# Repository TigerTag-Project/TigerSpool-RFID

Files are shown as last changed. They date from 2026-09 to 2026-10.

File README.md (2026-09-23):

<p align="center">
  <picture>
    <source media="(prefers-color-scheme: dark)"  srcset="assets/logo-tigertag-head-dark.svg">
    <source media="(prefers-color-scheme: light)" srcset="assets/logo-tigertag-head.svg">
    TigerTag
  </picture>
</p>

<h1 align="center">TigerSpool RFID</h1>

<p align="center">
  <strong>Tap a spool on the box. The filament lands in the right printer slot.</strong><br>
  A 2.0" touchscreen, a PN532 reader, and no typing.
</p>

<p align="center">
  
  
  
  
  
</p>

<p align="center">
  <a href="https://tigertag-project.github.io/TigerSpool-RFID/">
    Install TigerSpool from your browser
  </a>
</p>

<p align="center">
  <a href="#what-it-is">What it is</a>
  &nbsp;&middot;&nbsp;
  <a href="#before-you-start">Before you start</a>
  &nbsp;&middot;&nbsp;
  <a href="#quick-start">Quick start</a>
  &nbsp;&middot;&nbsp;
  <a href="#build-it-yourself">Build one</a>
</p>

<p align="center">
  The TigerTag system: a TigerPOD reader, Tiger Studio Manager on a desktop, and the TigerTag app on a phone
</p>

<p align="center">
  <sub>The TigerTag system. A TigerSpool is the device that takes a spool's
  identity and puts it into a printer's slot.</sub>
</p>

---

**TigerSpool RFID** is open-source firmware for a small box that sits next to
your 3D printer. Hold a spool carrying a TigerTag NFC chip against it, pick a
slot on the touchscreen, and the box writes the filament into that slot on the
printer — material, brand, colour and temperatures. No app, no keyboard, no
retyping what the tag already knows.

MIT licensed. Built with PlatformIO for the ESP32-S3.

---

## What it is

Your printer already has a slot list. Your filament already carries its own
identity. TigerSpool is the thirty centimetres between them.

- **Tap a slot, present the spool, done.** There is nothing to confirm: the
  assignment leaves for the printer as soon as the tag is read, over the
  printer's own protocol, and the box tells you which slot to load.
- **Scan mode: what is this spool?** Put one on the reader and the box shows
  what the chip holds - colour, material, brand, the two temperature windows,
  the drying instruction, what is left on it, and whether the tag is certified.
  No printer involved.
- **Your printers come from your account.** They are configured once, in Tiger
  Studio Manager, and every TigerSpool you own reads the same list.
- **It speaks nine languages** - English, French, German, Spanish, Italian,
  Polish, both Portuguese and Chinese - and asks which one before anything else.
- **It updates itself.** Over the air, verified, from this repository's releases.

## Before you start

**This is the part that catches people out, so it is first.**

A TigerSpool has no keyboard and no way to type a printer's address, and that is
deliberate — it reads your printers from your TigerTag account instead. Which
means two things have to exist before the box is useful:

### 1. A TigerTag account, created in Tiger Studio Manager

**[Tiger Studio Manager](https://github.com/TigerTag-Project/TigerTag-Studio-Manager)**
is the desktop application for the ecosystem. Install it and create an account
there. That account is what the TigerSpool signs in to — by e-mail, or with
Google through a QR code, so you never type a password on a 2" screen.

Without an account, the box gets through Wi-Fi setup and then has nothing to
sign in to.

<p align="center">
  Tiger Studio Manager showing a filament library and a printer's slots
</p>

<p align="center">
  <sub>Tiger Studio Manager. Your filaments and your printers live here — the box
  reads this list, it does not build it.</sub>
</p>

### 2. Your printers, added in Tiger Studio Manager

Adding a printer means Tiger Studio finds it on your network, or you enter its
address and access code, and stores it against your account.

**If you have not done this, the printer list on the box will be empty.** That is
not a fault and there is nothing to fix on the device — it is showing you exactly
what your account contains. Add the printer in Tiger Studio, and it appears on
the box at the next sync.

The same is true for the details: the access code, the IP address, the brand and
model all come from there. TigerSpool reads that list; it does not build it.

> **In short:** Tiger Studio Manager → create an account → add your printers →
> *then* set up the box.

## Quick start

### Step 1 — install from your browser

**Plug the board into your computer → click Install → wait a minute.** Use the
button at the top of this page. It writes the bootloader, the partition table,
the boot selector and the firmware.

Chrome, Edge or Opera, on a desktop or laptop. Safari and Firefox do not
implement WebSerial and no mobile browser does — the page says so rather than
failing quietly.

### Step 2 — set it up on the box

1. **Pick your language.** Nine of them, before anything else.
2. **Join Wi-Fi.** The box shows a QR code. Scan it with your phone, and a page
   opens listing the networks it can see. Pick yours, type the password on your
   phone, and the box joins — no reboot, nothing typed on the small screen.
3. **Sign in.** E-mail and password, or Google through a second QR code.
4. **Your printers arrive.** From your account, as configured in Tiger Studio.
   The box's address on your network (`http://tigerspool-xxxx.local/`) shows
   who is signed in, lists those printers with a switch for each, syncs them
   again, and signs out - all from a phone.

Then tap the slot you want and hold a tagged spool against the box. It is sent
to the printer as soon as it is read - there is nothing to confirm - and the
box then tells you where to put it.

That last part is the one people miss: **it tells the printer what the spool
is, it does not load it.** Putting the spool in that slot - the CFS, the AMS,
the ACE unit, whatever your printer calls its tray - is still yours to do.

From then on it updates itself over the air.

### Build it yourself

```bash
git clone https://github.com/TigerTag-Project/TigerSpool-RFID.git
cd TigerSpool-RFID

bash scripts/flash.sh --monitor
```

That builds the firmware, flashes it over USB and opens the serial console.
Requires [PlatformIO Core](https://docs.platformio.org/en/latest/core/installation/).

An ordinary flash **keeps your Wi-Fi credentials, your account session and your
printers** — nothing it writes touches the NVS partition. `--erase` wipes the
chip and is how you get a genuine first-boot again.

## Hardware

One board, one reader, four wires. The electronics are identical for every
printer brand — only the 3D-printed shell changes.

| Qty | Component | Link |
|---|---|---|
| 1 | Waveshare ESP32-S3-Touch-LCD-2 — 240×320 IPS touch, ESP32-S3**R8**, 16 MB flash, 8 MB octal PSRAM. Screen, touch and MCU on one board | [buy](https://link.amazon/B06RoLfDi) |
| 1 | PN532 **V3** NFC module — DIP switches, set to **HSU (UART)**: both switches `0` / OFF, not I²C, not SPI | [buy](https://link.amazon/B0iJgHVtP) |
| 1 | USB-C to USB-A cable **that carries data** — a charge-only cable makes a working board look dead: no serial port ever appears | [buy](https://link.amazon/B00Xg3WT4) |
| — | Four jumper wires — 3V3, GND, TX, RX | ships with the PN532 |
| 1 | 3D-printed case — one per printer brand, plus a desktop stand | [models/](models/) |
| *opt.* | Magnetic USB connector — the port is the one part handled every day; the cable lets go instead of the socket | [buy](https://link.amazon/B0bWVIBa0) |
| *opt.* | 3.7 V 1000 mAh LiPo cell, PH1.25 — charged over USB, and the box runs from it with the cable out. Settings then gains a **Battery** entry; without a cell it is not there. **Check the polarity** | [buy](https://link.amazon/B0fL0jjf3) |

**About 40 €** in total, plus filament.

> Some of the links above are Amazon affiliate links: buying through them pays
> the project a small commission at no cost to you. Nothing on this list is
> chosen because it is affiliated — any equivalent module works.

Full parts list: **[hardware/BOM.md](hardware/BOM.md)** ·
Wiring: **[docs/WIRING.md](docs/WIRING.md)** and **[hardware/pinout.md](hardware/pinout.md)**

<p align="center">
  <a href="docs/WIRING.md">
    Wiring diagram: ESP32-S3-Touch-LCD-2 to PN532 — 3V3, GND, TX to SDA, RX to SCL
  </a>
</p>
<p align="center">
  <sub><a href="https://app.cirkitdesigner.com/project/7a6c0887-8e44-4303-81b3-be51aab4b40a">Interactive schematic in Cirkit Designer</a></sub>
</p>

> **The reader goes on GPIO43/44.** Not GPIO6/7 — that pair is an I²C bus with
> pull-ups on this board. A PN532 wired there powers up, answers, and returns
> random UIDs with failing reads. It looks like a bad tag or a bad antenna. It is
> neither, and it costs a day. Follow [docs/WIRING.md](docs/WIRING.md) exactly.

## Printer support

**"Any printer" is the goal, not a claim about today.** The current state of
every brand is in **[docs/PRINTER-COMPATIBILITY.md](docs/PRINTER-COMPATIBILITY.md)**,
which grades each on three levels — ✅ automatic, ⚙️ one setup step,
🧪 experimental. Read it before buying parts for a specific printer.

| Brand | Firmware support | Transport |
|---|---|---|
| **Creality** | ✅ implemented, proven on hardware | WebSocket |
| **FlashForge** | ✅ implemented, proven on hardware | HTTP |
| **Bambu Lab** | ✅ implemented, proven on hardware - LAN and cloud mode | MQTT over TLS |
| **Snapmaker** | ✅ implemented, proven on hardware | Moonraker over WebSocket |
| **Elegoo** | ✅ implemented, reading proven on hardware | MQTT |
| **Anycubic** | ✅ implemented, reading proven on hardware - LAN mode | MQTT over TLS |

A Bambu Lab printer in **cloud mode** is read-only: its spools are shown, but a
tag cannot be written to it - Bambu's cloud does not accept the command. Switch
the printer to LAN mode to write.

Slot names match the ones the printer and Tiger Studio use — `Ext.` plus
`1A`–`1D` on Creality and FlashForge, `A1`–`A4` then `B1`–`B4` on Bambu,
`E1`–`E4` on Snapmaker, `S1`–`S4` on Elegoo, `A1`–`A4` per ACE unit on
Anycubic. The table and its two traps are in the compatibility document.

## How many printers at once

**The limit is not a number of printers - it is how much memory their
connections take.** One TigerSpool has a fixed budget of **160 load slots**,
where one load slot is one kilobyte of the chip's internal RAM, and each printer
takes what its connection costs:

| Printer | Load slots |
|---|---|
| First Bambu Lab in cloud mode | 50 |
| Each further Bambu Lab in cloud mode | 4 - they share one connection |
| Bambu Lab in LAN mode | 50 |
| Anycubic | 41 |
| Creality | 6 |
| Snapmaker | 5 |
| Elegoo | 3 |
| FlashForge | 2 |

The difference is encryption: a Bambu or an Anycubic talks over TLS, which is
what memory goes on; the others do not. So ten Elegoos fit where three LAN
Bambus do not.

**Settings > Printers** shows how full the budget is as a percentage. A printer
that would not fit is refused when you switch it on, with the reason on the
screen, rather than connecting and failing later. The measurements, the reasons
for 160, and what the budget does not account for are in
**[docs/CONNECTION-BUDGET.md](docs/CONNECTION-BUDGET.md)**.

## Documentation

| | |
|---|---|
| [ARCHITECTURE.md](docs/ARCHITECTURE.md) | Layering, the state machine, why a backend knows nothing about the screen |
| [ONBOARDING.md](docs/ONBOARDING.md) | The first-boot journey, screen by screen |
| [WIFI-PROVISIONING.md](docs/WIFI-PROVISIONING.md) | The QR code and the captive portal |
| [ACCOUNT-PAIRING.md](docs/ACCOUNT-PAIRING.md) | E-mail and Google sign-in, and why RFC 8628 was rejected |
| [ACCOUNT-DATA.md](docs/ACCOUNT-DATA.md) | The shape a printer arrives in |
| [OTA.md](docs/OTA.md) | Partitions, the manifest, and what is settled before the first release |
| [PRINTER-COMPATIBILITY.md](docs/PRINTER-COMPATIBILITY.md) | Per-brand status and slot naming |
| [CONNECTION-BUDGET.md](docs/CONNECTION-BUDGET.md) | How many printers at once: load slots, every measurement behind them, why 160 |
| [PRESENCE.md](docs/PRESENCE.md) | How a box declares itself to the account, so Tiger Studio can list it |
| [WIRING.md](docs/WIRING.md) | The four wires |
| [ROADMAP.md](docs/ROADMAP.md) | What is deliberately not done yet, and what has to be decided first |

Contributors and agents start at **[AGENTS.md](AGENTS.md)** and
**[CODEMAP.md](CODEMAP.md)**.

## Known limitations

Written down rather than discovered.

- **The firmware is not signed.** Its update connection is verified against the
  root certificate store, so the box knows who it is talking to — but not who
  produced the image. The reasoning and the condition for changing that are in
  [docs/OTA.md](docs/OTA.md).
- **At most three printers that use TLS at once** - Bambu Lab in LAN mode and
  Anycubic, with every cloud Bambu on an account counting as one. It is the
  chip's internal RAM, and the load budget enforces it; see
  [docs/CONNECTION-BUDGET.md](docs/CONNECTION-BUDGET.md). The two ways past it
  are in [docs/ROADMAP.md](docs/ROADMAP.md).
- **A battery has to be declared, in Settings.** The board has no way to tell
  whether a cell is on its connector - no sense line, and the two indirect
  signals were each measured wrong on real hardware - so it asks instead of
  guessing. Until someone answers, it reports no battery.
- **Anycubic in cloud mode is not supported**, only LAN mode.
- **A printer is identified by its position in your account's list.** Reordering
  it in Tiger Studio can move a per-printer setting to the wrong machine. Tracked
  in [docs/reviews/](docs/reviews/).

## Part of the TigerTag ecosystem

TigerTag is an open NFC identification standard for 3D-printing materials. A
spool carries its own identity, and every device in the system reads the same
one.

- **[Tiger Studio Manager](https://github.com/TigerTag-Project/TigerTag-Studio-Manager)** — desktop printer and filament manager. **Start here**: it is where an account is created and printers are declared.
- **[TigerTag-RFID-Guide](https://github.com/TigerTag-Project/TigerTag-RFID-Guide)** — the protocol specification and public registry
- **[TigerSystem-Docs](https://github.com/TigerTag-Project/TigerSystem-Docs)** — ecosystem source of truth
- **[Tiger-Scale-V3](https://github.com/TigerTag-Project/Tiger-Scale-V3)** — the connected filament scale
- **[TigerPOD](https://github.com/TigerTag-Project/TigerPOD)** — open desktop NFC reader/writer
- **SDKs** — [Python](https://github.com/TigerTag-Project/TigerTag-SDK-Python) · [JavaScript](https://github.com/TigerTag-Project/TigerTag-SDK-JS)

## Contributing

Issues and pull requests are welcome. [CONTRIBUTING.md](CONTRIBUTING.md) has the
conventions; the short version is that `bash scripts/verify.sh` passes before
anything is reported as done, and everything committed is in English.

Security reports: [SECURITY.md](SECURITY.md).

## License

[MIT](LICENSE) — build it, sell it, fork it.

Third-party components keep their own licenses; see
[THIRD_PARTY_LICENSES.md](THIRD_PARTY_LICENSES.md). "TigerTag" and "TigerSpool"
are project names, not a license to imply endorsement — the terms for using them
on a product you sell are in [TRADEMARK.md](TRADEMARK.md).

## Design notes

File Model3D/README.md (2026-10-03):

# 3D-printable cases

**The [desktop stand](0.Desktop/) is the base model.** It stands beside any
printer, and it is the one to print if you are not sure. Every other model is a
**printer integration**: the same TigerSpool in a shell that clips onto one
printer's own screen.

<p align="center">
  The desktop stand, spool on the left and spool on the right
</p>

| Model | Kind | MakerWorld | Files |
|---|---|---|---|
| Desktop stand, spool on the left | base, any printer | [print it](https://makerworld.com/models/3360492-tigerspool-desktop-stand-spool-on-the-left) | [`0.Desktop/`](0.Desktop/) |
| Desktop stand, spool on the right | base, any printer | [print it](https://makerworld.com/models/3360619-tigerspool-desktop-stand-spool-on-the-right) | [`0.Desktop/`](0.Desktop/) |
| Creality K2, K2 Pro | integration, clips onto the screen | [print it](https://makerworld.com/models/3361291-tigerspool-for-creality-k2-and-k2-pro) | [`2.Creality/K2-K2Pro/`](2.Creality/K2-K2Pro/) |
| FlashForge Creator 5, 5 Pro | integration, clips onto the screen | [print it](https://makerworld.com/models/3361301-tigerspool-rfid-for-flashforge-creator-5-and-5-pro) | [`4.FlashForge/Creator5-5Pro/`](4.FlashForge/Creator5-5Pro/) |
| Bambu Lab A1, A2L | integration, clips onto the screen | not yet | [`1.BambuLab/A1-A2/`](1.BambuLab/A1-A2/) |
| Anycubic Kobra 3, every model | integration, clips onto the screen | not yet | [`6.Anycubic/Kobra3-Series/`](6.Anycubic/Kobra3-Series/) |

Each brand directory lists its models. On MakerWorld every page carries the
full Bambu Studio project and the whole build guide; the bare parts, the other
slicers' projects and the Fusion sources are here.

---

## The rule that governs every model in this directory

**Only the shell changes. The electronics, the wiring and the connectors are
strictly identical across every model.**

Same Waveshare ESP32-S3-Touch-LCD-2. Same PN532. Same four wires on the same pins.
Same USB-C entry. A TigerSpool built for a Bambu Lab and one built for a Creality
are the same device in a different jacket, and either firmware image runs on
either one.

This is not a convention. It is what makes the project shippable:

- **One firmware.** No per-model build, no variant to pick in the installer, no
  way to flash the wrong image.
- **One bill of materials.** [../hardware/BOM.md](../hardware/BOM.md) is complete
  for every model.
- **One set of wiring instructions.** [../docs/WIRING.md](../docs/WIRING.md)
  is correct for every model.
- **Anyone can add a model** without touching a line of code.

A design that needs a different board, a different reader, extra components, or a
change to the pinout **is not a TigerSpool model**. It is a fork, and it is
welcome as one — under a different name.

---

## What each model has to do

Different only in how it mounts. Every one of them has to:

| Requirement | Why |
|---|---|
| Hold the PN532 antenna **2–4 cm** from where a spool naturally rests | That is the reader's entire range ([../docs/WIRING.md](../docs/WIRING.md)) |
| Keep the antenna **away from the display's metal back** and any ground plane | Both destroy what little range there is |
| Present the 2.0" screen at a readable, tappable angle | It is a touchscreen, used standing up |
| Leave the USB-C port reachable | Power, and recovery flashing |
| Print without supports where possible, and on a printer of the brand it is for | It is a case for that printer; it should print on it |
| Say clearly **where to hold the spool** | Moulded, embossed, or an obvious surface — not in a manual |

---

## Directory layout

```
Model3D/
├── TEMPLATE.md                the README every model starts from
├── 0.Desktop/                 free-standing, fits any printer - the universal one
├── 1.BambuLab/                one numbered directory per brand ...
│   ├── README.md              ... listing its models
│   └── X1C/                   ... and one directory per printer model
├── 2.Creality/
├── 3.Snapmaker/
├── 4.FlashForge/
├── 5.Elegoo/
└── 6.Anycubic/
```

Two levels, and only two: **brand, then printer model.** A case that fits a
whole range goes in the brand directory under the name of that range (`P1/`
for the P1P and the P1S); one that fits a single machine takes that machine's
name (`K2-Plus/`). A model that fits every printer is not a brand model at all:
it belongs in `0.Desktop/`, or next to it.

**A directory here is about physical mounting, not firmware support.** A case
can be designed for a printer before its network protocol works, so a directory
existing says nothing about whether the device talks to that printer.
[../docs/PRINTER-COMPATIBILITY.md](../docs/PRINTER-COMPATIBILITY.md) is the
authority on what actually works.

### What goes in a model directory

```
K2-Plus/
├── README.md                  from ../TEMPLATE.md
├── Images/                    what it looks like - a photo beats a render
├── Source/                    the editable design: .step, .f3d
├── OriginalFiles/             the parts as exported, one file each, no slicer settings
├── BambuStudio/               one directory per slicer the project is saved from
│   └── *.3mf
└── CrealityPrint/
    └── *.3mf
```

| What | Why |
|---|---|
| `README.md` | Which printers it fits, what to print and in what, how it goes together |
| `Images/` | Nobody downloads a case they cannot see. The slicer's own previews can be taken out of a 3MF (`Metadata/plate_1.png`, `top_1.png`) until there is a photo |
| `Source/` | So the next person can adapt it instead of starting again. `.step` opens everywhere; a native file (`.f3d`) is welcome beside it |
| `OriginalFiles/` | The bare parts, for any slicer and any printer |
| `<Slicer>/*.3mf` | A 3MF saved from a slicer carries the orientation, the supports and the plate for that slicer's printers, and is tied to it. One directory per slicer: `BambuStudio/`, `CrealityPrint/`, `FlashStudio/`, `OrcaSlicer/`, `PrusaSlicer/` |

Variants of one design (the desktop stand with the spool on the left or on the
right) are told apart by the file name, or by a `Left/` and `Right/` level where
there are several files per variant.

### Names

**Directories** are written to be read: capitals where they help (`BambuStudio`,
`OriginalFiles`, `K2-Plus`), a number in front of the top-level ones to set
their order. **Files** are lower case with hyphens:
`tigerspool-<model>-<variant>-<part>.3mf`, for example
`tigerspool-desk-left-display-cover.3mf`. **No spaces anywhere**: a space breaks
every link to the path in a README. `scripts/check-models.py` enforces all
three.

### Before a photo is committed

A phone photo records the phone, the time and **the GPS position it was taken
at**. Publish a copy with none of it, scaled to something a page can load:

```bash
ffmpeg -i IMG_1234.jpeg -vf "scale='min(2000,iw)':-2" -map_metadata -1 -q:v 3 \
    Model3D/<Brand>/<Model>/Images/tigerspool-<model>-photo-<view>.jpg
```

`-map_metadata -1` drops the metadata; ffmpeg applies the phone's rotation to
the pixels first, so the picture stays the right way up. Look at the
background too: a photo on a desk shows whatever else is on that desk.
`verify.sh` refuses a picture that still carries EXIF.

### Before a 3MF is committed

A slicer project records more than geometry. It keeps the **full path** of the
file each object was imported from - a user name and a folder layout, on a
public repository - and every object's name as the designer typed it.

```bash
python3 scripts/clean-3mf.py Model3D/<Brand>/<Model>/<Slicer>/*.3mf
```

cuts every source path down to its file name and prints every object name, so
you read them before anyone else does. `verify.sh` refuses a 3MF that still
carries a path.

## Contributing a model

1. Read the rule at the top. If your design needs different electronics, it is a
   fork, not a model.
2. **Print it and build one.** Fit, screen angle and read distance are not
   things a render tells you.
3. **Measure the read distance through the shell.** A case that pushes the
   antenna past ~4 cm produces a device that looks fine and reads nothing.
4. Copy [TEMPLATE.md](TEMPLATE.md) to your directory as `README.md` and fill
   it in: print settings, a photo, which printers it fits.
5. Include the editable source (`.step`, and the native file if you have one)
   so the next person can adapt it.
6. Run `scripts/clean-3mf.py` on your projects, then `bash scripts/verify.sh --quick`.
7. Add a row to the brand's README, and open a PR. See [../CONTRIBUTING.md](../CONTRIBUTING.md).

A model that has been printed and used beats a model that has been designed.

---

## Licensing

Model files contributed here are MIT-licensed like the rest of the repository
([../LICENSE](../LICENSE)). Do not contribute geometry derived from a
manufacturer's proprietary CAD, or from a model whose own license does not permit
redistribution.

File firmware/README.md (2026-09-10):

# firmware/

The TigerSpool firmware: one PlatformIO project, one environment, `tigerspool`,
for the Waveshare ESP32-S3-Touch-LCD-2 with a PN532 reader.

## Layout

```
firmware/
├── platformio.ini          env: tigerspool
├── partitions.csv          two OTA slots, frozen - docs/OTA.md
├── include/                board and LVGL configuration, generated headers
│   ├── version.h           TIGERSPOOL_FW_VERSION, the one version macro
│   └── tigertag_db.h       generated from tools/tigertag_db - never hand-edited
├── lib/
│   └── PN532/              vendored reader driver - ONE copy, patches documented
├── tools/tigertag_db/      mirror of the public TigerTag reference tables
└── src/
    ├── main.cpp            the state machine and the only writable device state
    ├── printer.h           the backend interface and the printer record
    ├── printer_budget.h    how many printers at once - docs/CONNECTION-BUDGET.md
    ├── backend_*.cpp       one backend per brand, one object per printer
    ├── bambu_cloud.cpp     the TLS session every cloud Bambu on an account shares
    ├── reader.cpp          PN532 use, TigerTag decoding
    ├── tigertag_cloud.cpp  account sign-in, pairing, printer import
    ├── tt_db.cpp           reference-table lookups, compiled and downloaded
    ├── webcfg.cpp          captive portal, LAN page, /screen.bmp, /api/*
    ├── i18n.cpp            every on-screen string, in eight languages
    ├── net/                captive DNS, OTA, TLS helpers
    └── ui/                 LVGL screens, theme, icons, generated fonts
```

What each file owns, what it must not be asked to do, and the landmines to read
before editing it are in [../CODEMAP.md](../CODEMAP.md). This tree is the
overview; the map is the reference.

## Rules for this tree

**No credentials, ever.** Not Wi-Fi, not printer access codes, not API keys with
authority. Everything comes from NVS at runtime. The published binary is the same
for every user. See [../SECURITY.md](../SECURITY.md).

**One copy of the vendored library.** The prototype carries three, which have
already drifted into different behaviour —
[../docs/MIGRATION.md](../docs/MIGRATION.md#the-vendored-pn532-library). Patches
to a vendored library carry a comment saying what breaks without them.

**English only.** Comments, identifiers, log messages, commit messages.
User-facing strings go through the i18n layer (`i18n.cpp`), in every language
at once.

**Hardware facts get a comment explaining why.** Every constant that looks
arbitrary — a delay, a page range, a retry count — is arbitrary-looking because
it was expensive to find. Say what breaks if it changes.

## Build

```bash
pio run -e tigerspool                 # compile
bash ../scripts/flash.sh --monitor    # build, flash over USB, open the console
bash ../scripts/verify.sh             # the guards CI runs, plus a build
```

`flash.sh` checks the board's MAC before writing, so it cannot flash the wrong
device on a bench with several plugged in.

Most users will never do this — they install from the browser, and after that
the device updates itself over the air ([../docs/OTA.md](../docs/OTA.md)).

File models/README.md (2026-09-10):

# 3D-printable cases

> **Status: empty.** The directory structure and the rules are here. No model
> files exist yet.

---

## The rule that governs every model in this directory

**Only the shell changes. The electronics, the wiring and the connectors are
strictly identical across every model.**

Same Waveshare ESP32-S3-Touch-LCD-2. Same PN532. Same four wires on the same pins.
Same USB-C entry. A TigerSpool built for a Bambu Lab and one built for a Creality
are the same device in a different jacket, and either firmware image runs on
either one.

This is not a convention. It is what makes the project shippable:

- **One firmware.** No per-model build, no variant to pick in the installer, no
  way to flash the wrong image.
- **One bill of materials.** [../hardware/BOM.md](../hardware/BOM.md) is complete
  for every model.
- **One set of wiring instructions.** [../docs/WIRING.md](../docs/WIRING.md)
  is correct for every model.
- **Anyone can add a model** without touching a line of code.

A design that needs a different board, a different reader, extra components, or a
change to the pinout **is not a TigerSpool model**. It is a fork, and it is
welcome as one — under a different name.

---

## What each model has to do

Different only in how it mounts. Every one of them has to:

| Requirement | Why |
|---|---|
| Hold the PN532 antenna **2–4 cm** from where a spool naturally rests | That is the reader's entire range ([../docs/WIRING.md](../docs/WIRING.md)) |
| Keep the antenna **away from the display's metal back** and any ground plane | Both destroy what little range there is |
| Present the 2.0" screen at a readable, tappable angle | It is a touchscreen, used standing up |
| Leave the USB-C port reachable | Power, and recovery flashing |
| Print without supports where possible, and on a printer of the brand it is for | It is a case for that printer; it should print on it |
| Say clearly **where to hold the spool** | Moulded, embossed, or an obvious surface — not in a manual |

---

## Directory layout

```
models/
├── desktop/      free-standing, sits on a bench or desk — the universal one
├── bambulab/     mounts to a Bambu Lab printer or AMS
├── creality/     mounts to a Creality printer or CFS
├── snapmaker/    mounts to a Snapmaker
├── flashforge/   mounts to a FlashForge
├── elegoo/       mounts to an Elegoo
└── anycubic/     mounts to an Anycubic
```

**A directory here is about physical mounting, not firmware support.** A case
can be designed for a printer before its network protocol works, so a directory
existing says nothing about whether the device talks to that printer.
[../docs/PRINTER-COMPATIBILITY.md](../docs/PRINTER-COMPATIBILITY.md) is the
authority on what actually works.

### What goes in a model directory

| File | |
|---|---|
| `README.md` | Which printers it fits, print settings, assembly notes, photo |
| `*.3mf` | Preferred — carries orientation, supports and plate layout |
| `*.stl` | One per part, pre-oriented for printing |
| `*.step` | Editable source, if available. Please include it. |

`desktop/` is the reference. Start there when designing a new one.

---

## Contributing a model

1. Read the rule at the top. If your design needs different electronics, it is a
   fork, not a model.
2. **Print it and build one.** Fit, screen angle and read distance are not
   things a render tells you.
3. **Measure the read distance through the shell.** A case that pushes the
   antenna past ~4 cm produces a device that looks fine and reads nothing.
4. Add a `README.md` with print settings, a photo, and which printers it fits.
5. Include editable source (`.step` or `.3mf`) so the next person can adapt it.
6. Open a PR. See [../CONTRIBUTING.md](../CONTRIBUTING.md).

A model that has been printed and used beats a model that has been designed.

---

## Licensing

Model files contributed here are MIT-licensed like the rest of the repository
([../LICENSE](../LICENSE)). Do not contribute geometry derived from a
manufacturer's proprietary CAD, or from a model whose own license does not permit
redistribution.

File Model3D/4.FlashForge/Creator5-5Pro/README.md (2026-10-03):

# FlashForge Creator 5 and Creator 5 Pro

The case on a Creator 5 Pro, clipped onto its screen Close-up of the case on the printer

**Print it from MakerWorld:
[TigerSpool for FlashForge Creator 5 and 5 Pro](https://makerworld.com/models/3361301-tigerspool-rfid-for-flashforge-creator-5-and-5-pro)**

A printer integration of the [desktop stand](../../0.Desktop/) for the
FlashForge Creator 5 and Creator 5 Pro: the same TigerSpool, in a case that
clips onto the printer's screen, with the TigerSpool screen and the reader
beside it - where the spools go into slots 1A to 1D.

## Recommended: the FlashForge × TigerSystem firmware

TigerSpool talks to the printer over your local network. With FlashForge's
standard firmware, **turning LAN mode on turns FlashForge Cloud off**. The
FlashForge × TigerSystem firmware - an official FlashForge build, developed by
their engineering team at TigerTag's request - keeps both on at once. It is
free.

| | Standard firmware | FlashForge × TigerSystem |
|---|---|---|
| FlashForge Cloud - app, remote access | ✓ | ✓ |
| LAN - local tools on your network | ✓ | ✓ |
| Both at the same time | ✕ | ✓ |
| Tiger Studio, Tiger NFC Connect and TigerSpool with Cloud on | ✕ | ✓ |

Download: [Creator 5](https://tigertag-project.github.io/FlashForge-TigerTag-Creator5-Firmware-Lan-and-Cloud/download/creator5/) ·
[Creator 5 Pro](https://tigertag-project.github.io/FlashForge-TigerTag-Creator5-Firmware-Lan-and-Cloud/download/creator5pro/).
It installs from a FAT32 USB drive, the file at its root, printer off; switch
on and it installs itself. Then turn LAN mode on. **Do not accept the printer's
own online update afterwards** - it puts the standard firmware back, and Cloud
+ LAN with it; reinstall from USB if it happened.

Thank you, FlashForge: opening a printer to an ecosystem that is not your own
is a rare decision.

## Parts

| Part | File |
|---|---|
| Frame | [`tigerspool-creator5-frame.3mf`](OriginalFiles/tigerspool-creator5-frame.3mf) |
| Cover | [`tigerspool-creator5-cover.3mf`](OriginalFiles/tigerspool-creator5-cover.3mf) |
| RFID reader holder | [`tigerspool-creator5-rfid.3mf`](OriginalFiles/tigerspool-creator5-rfid.3mf) |
| Everything, one plate (Bambu Studio) | [`tigerspool-creator5-full.3mf`](BambuStudio/tigerspool-creator5-full.3mf) |
| Everything, one plate (FlashForge's Flash Studio, for the Creator 5) | [`tigerspool-creator5-full.3mf`](FlashStudio/tigerspool-creator5-full.3mf) |

The bare parts carry geometry only, for any slicer; the two slicer projects
carry the orientation, the supports and the settings below.

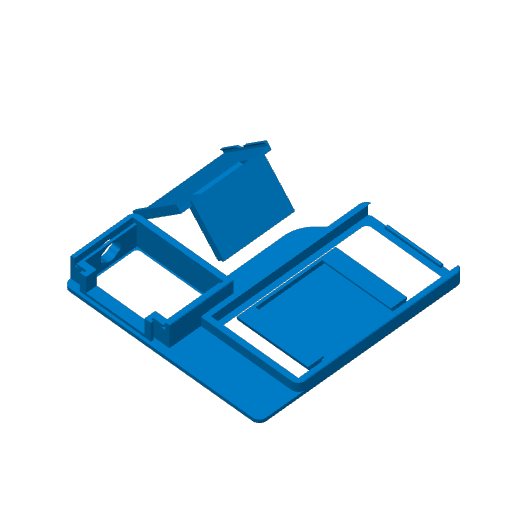
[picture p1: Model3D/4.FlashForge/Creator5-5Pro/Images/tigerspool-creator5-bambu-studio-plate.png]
The parts on the Bambu Studio plate


## Print settings

| Setting | Bambu Studio | Flash Studio |
|---|---|---|
| Printer | A1 mini, 0.4 mm nozzle | Creator 5, 0.4 mm nozzle |
| Layer height | 0.20 mm | 0.08 mm |
| Walls | 3 | 2 |
| Infill | 15 % | 15 % |
| Supports | tree, placed by hand - they are in the project | the same |
| Material | PLA (Bambu PLA Basic in the project), two colours | PLA |

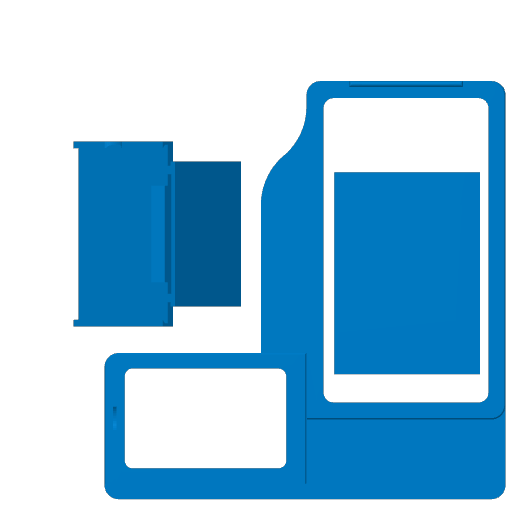
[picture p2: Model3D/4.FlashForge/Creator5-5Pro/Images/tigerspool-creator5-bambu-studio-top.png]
The plate from above


## Source

[`Source/tigerspool-creator5.f3d`](Source/tigerspool-creator5.f3d) - the Fusion design.

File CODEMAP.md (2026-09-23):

# Code map

**The [Landmines](#landmines) table is this file.** Everything above it is the
short list of module facts that `ls` and `grep` do not give you; everything a
grep would have told you has been deliberately left out.

No line numbers are recorded here: nothing verifies them, and a number nothing
verifies is a number that lies. Grep for the symbol. If a file has outgrown what
this says, say so rather than working around it.

Build-level and hardware-level facts live in [CLAUDE.md](CLAUDE.md) and are not
repeated here.

## Modules worth a note

| File | What is not obvious |
|---|---|
| `main.cpp` | Owns the state machine and the only writable copy of device state — and also owns the display device itself (`lcd`, and the PSRAM `canvas` sprite that exists solely so `/screen.bmp` has something to serialise). It draws no widgets, and must not start: screens render from state passed in. It also carries an inline Creality LAN scanner, which is not where anyone looks for it. |
| `webcfg.cpp`, account page | Signed in, `/login` is the account page, and it **never syncs or switches anything itself**. Its handlers run on the loop task: a sync there nested a TLS handshake in a web handler, overflowed the loop's 8 KB stack on every email sign-in, and held the screen still for the whole sync. So a handler calls `ttcloud::requestSync()` and the loop starts the task; a printer switch is a mask read by `takePrinterSwitch()` and applied by `main.cpp` through `tryToggle()`, the device's own switch and budget check. `/api/account` answers anyone on the LAN, so it carries names, brands and addresses and never a serial or an access code. |
| `webcfg.cpp` | Serves **two** web interfaces — the captive portal for setup, and a separate legacy configuration page over the LAN once provisioned — and has **two** independent Wi-Fi scanners, one async and JSON for the portal, one blocking and HTML for the legacy page. "Change the web page" or "fix the scan" usually means changing the wrong one. |
| `tt_db.cpp` | The TigerTag reference tables exist **twice**, and every lookup goes through here rather than through `tigertag_db.h`. The compiled tables are the floor - what a brand-new box knows offline - and the downloaded ones in LittleFS are preferred when they parse. The fallback is per table, not all-or-nothing, so a corrupt brand file does not throw away a good material file. Calling `tt_material()` directly bypasses the whole mechanism and looks identical until a spool from last month reads as `brand#48804`. The material table keeps more than labels - `crealityID`, `crealityPressureAdvance` and the recommended nozzle window, in the download and in `TT_MATERIAL_INFO` - and `materialInfo()` answers from the same layer as `material()`. |
| `printer_budget.h` | Decides whether a printer may be **switched on**, in *load slots* - one is a kilobyte of internal RAM. It never sees memory: the prices are constants taken from `/api/memtest`, and `docs/CONNECTION-BUDGET.md` holds the measurements they must stay equal to. A new brand with no entry in `loadSlotsFor()` costs 0 and is never refused. "Load slot", never plain "slot" - a slot is a spool tray everywhere else in this code. |
| `backend_bambu.cpp`, external spool | **Read as ams 255 / tray 254, written as ams 255 / tray 0 / slot 0.** A write to tray 254 is accepted and ignored by current firmware (X1C 01.12). The first report after a new MQTT connection carries an empty external tray before the real one. |
| `bambu_cloud.cpp` | One MQTT/TLS session shared by **every** cloud Bambu on the account; `backend_bambu.cpp` attaches and detaches, ref-counted. Reports are routed by the serial in the topic and nothing else - a report is never handed to a printer it did not name. So one cloud printer's "connected" is the session's, and closing one printer does not close the session while another is attached. LAN Bambus do not use it. |
| `filament_resolve.cpp` | Decides what a printer is sent for a spool - temperatures, material family, Creality material id, Bambu filament id, pressure advance, name - field by field from the TigerTag+ product endpoint, the chip, the material table, a default. **Pure**: no network, no Arduino, the endpoint's answer is handed in, so it is tested on a computer with injected answers. The chip never carries a printer's material id; only the endpoint and the table do. A plain TigerTag never gets the endpoint's answer considered, even if one is passed. |
| `product_api.cpp` | Fetches the product endpoint on a task, **started when a TigerTag+ is read** (for a Creality today), not when Send is pressed; Send waits only while that fetch is inside its 3 s budget. One cached answer, by product id. It asks main.cpp to stand background links down only if the heap was short of a handshake when it started: standing them down cost nothing during the request and 800-900 ms of loop AFTER it, while they dialled back. `/api/resolve` runs the whole resolution from query parameters without a spool and without sending. |
| `tigertag_cloud.cpp` | Its network calls are on a **mixed** regime, not a uniform one. The sync and the pairing start run on their own FreeRTOS tasks; `pairPoll()` and `signInWithCustomToken()` are called straight from the main loop and stall it for about a second each. Neither pattern is the rule, so check which one a call is on before adding another. |

### One board, three TLS talkers - and what it actually costs

The account sync, the firmware check and the reference-table update each open
their own `WiFiClientSecure`. Two at once is fine; **three is not** - the third
gets a refused connection. That is why the table update runs on its own clock
ninety seconds after boot rather than beside the update check, and skips while
either of the other two is talking. It was measured, as `HTTP -1` on every
attempt.

**Do not generalise that to printer sessions.** Those three verify against the
Arduino core's root CA bundle, and parsing it is most of what they cost. A
printer session is `setInsecure()` and is cheaper - but a TLS printer still
takes 40-48 KB of internal RAM against 2-6 KB for any other, and the device
holds about three TLS sessions before fragmentation stops the fourth. Every
measurement, and the load budget that enforces it (`printer_budget.h`), is in
[docs/CONNECTION-BUDGET.md](docs/CONNECTION-BUDGET.md). A one-off TLS request
beside three printer sessions gets room from the TLS stand-down in `main.cpp`,
not from the budget.

## Landmines

Each row is something the code does not say about itself, and that a session
already paid for. Read the row before editing what it names.

### Generated data

| Where | What you need to know |
|---|---|
| `tools/tigertag_db/gen_db.py` | **It refuses a label the panel cannot draw.** Every label is checked against the compiled font range before a byte is written, and the build stops on the first one outside it. Exactly two things are repaired instead of refused - a no-break space becomes a space, a superscript becomes its digit - and both are printed as warnings so the upstream defect stays visible. Adding a repair is a decision about what a brand name IS; see the comment above `NBSP` before making one. |

### Text on the screen

| Where | What you need to know |
|---|---|
| `i18n.cpp`, the `STR` table | **It is positional.** The `static_assert` checks the number of *rows* against the enum and nothing else. It does not check that a row has the right number of entries, that the languages sit in the enum's column order, or that no entry is empty. A language block one column out of place compiles cleanly and mistranslates that entire language. A row one entry short zero-fills the rest, and a NULL reaches `lv_label_set_text`. |
| `enum Lang` (`i18n.h`) and `LANG_SCHEMA` (`i18n.cpp`) | The chosen language is stored in NVS **as an index**. Reordering or removing an entry silently changes what a stored index means, and the device comes back up speaking something else. `LANG_SCHEMA` exists for exactly this: bump it in the same edit and the stale index is discarded instead of misread. |
| Any string or label that reaches the panel | The faces cover Latin-1 and Latin Extended-A, so accents draw — but **`0xA0` is excluded on purpose**, and everything above Extended-A is not, **except the Chinese characters the source already uses**: the faces carry a Noto Sans SC subset of exactly those (`scripts/cjk-chars.py`), so a Chinese string with one new character needs the faces regenerated before it can draw. LVGL draws a missing glyph as a blank box and logs nothing, so nothing fails until a user sees it; `check-ui-fonts.py` is what catches it first. This includes **data**: reference labels are validated against the same range at generation time, which is how two brand names carrying a no-break space were found. |

### LVGL and the screens

| Where | What you need to know |
|---|---|
| `ui/frame.cpp` vs `screen_setup.cpp::addBack()` | **Two different back affordances exist.** The header one is a 56 px button on `LV_EVENT_CLICKED`: a slight drag between press and release cancels it, which is what made going back feel unreliable on a touch panel. `addBack()` is a full-width strip on `LV_EVENT_PRESSED` with no pressed-state highlight, because the screen is gone before a highlight could render. Copy the wrong one and back becomes hard to hit again. |
| `ui/frame.cpp`, screen swap | `lv_scr_load(new)` comes **before** `lv_obj_del(old)`. Deleting first deletes the screen that is still active, and LVGL faults inside the next draw. |
| `battery.cpp` (is there a cell) | **The user says so.** There is no detection left, because none of it worked: the board has no sense line, the rail with an empty connector sits anywhere from 4.05 to 4.27 V depending on the board, and the charger's ripple - which a healthy cell damps - is not damped by a tired one. Measured on our two boards, the ripple test was wrong in both directions: one reported a battery it did not have, the other denied the pack it was running on. `battery::declare()` writes the answer to NVS (`bdecl`) and `present()` is that answer, full stop. Everything downstream - the percentage, the runtime, `battery_present` in the heartbeat - follows it. |
| `battery.cpp` (charging) | Charging is not a fact this board reports - there is no status line - so it is inferred from the SHAPE of the curve: a step of 5 mV at the pin between two readings is a cable moving, and over three minutes a rise of 3 mV means charging while it takes a fall of 6 to say otherwise. That asymmetry is deliberate: a nearly full cell on a charger is flat, and judged symmetrically it reads as a discharge. The charger's contribution to the voltage is measured from that same step and kept in NVS, because it is not a constant - it shrinks as the charger tapers, and a fixed value put a nearly full cell fifteen points low. |
| `battery.cpp` (the pin) | The ADC on GPIO5 measures the battery **rail**, not the battery, through a 200K/100K divider (so times three). On USB that rail is held up by the charger whether a cell is plugged in or not - which is why presence is declared rather than read, and charging is inferred from the curve rather than reported. |
| `ui/signal_level.h` | The dBm-to-arcs scale, header-only and free of LVGL so it can be compiled and run on a computer - which is how the hysteresis was checked, rather than by waiting for a signal to wobble at the right moment. It is written **twice**: here for the panel and as JavaScript in `net/portal_page.h` for the portal's network list. `scripts/check-signal-scale.py` fails when the two disagree. |
| `ui/lvgl_port.cpp` | LVGL runs in a task of its own, core 1, priority 2 - it draws and reads the touch panel while the main loop is blocked inside a socket, which is what a TLS handshake to a printer that is switched off does for 1.3 s. Two consequences. **LVGL is not reentrant**: every public function in `ui/` takes `lvgl_port::Lock`, and so does anything in `webcfg.cpp` that touches it. **Flags set from an LVGL event callback are set on that task** and read on the loop, so they are `volatile` - `s_tapped`, `s_back` and their kind. `lvgl_port::loop()` no longer pumps LVGL when the task is running; it yields, so a screen just built is on the glass before the loop moves on. |
| `ui/screen_home.cpp` | `show()` runs from the main loop on every iteration, so it must be idempotent. It guards on a cheap signature of everything it renders, and **anything that changes what is displayed must be inside that signature** — visibility was once outside it, so hiding a printer changed nothing on screen. Rebuilding unconditionally destroys rows under the user's finger and reads as a frozen device. |
| `ui/screen_home.cpp`, the two faces | One screen, two faces: `showMain()` draws the choice (printers or reader) and `show()` draws the printer list, into the SAME container and header. Each keeps its own redraw signature, so the face itself is in the test - without it a face whose signature had not changed since it was last shown declines to rebuild and the other face's rows stay on screen. `headerFace()` owns what the header shows: the account and Wi-Fi icons are on the choice only, because a chevron, a title and three icons do not fit across 240 px. |
| `ui/screen_read.cpp` | Reader mode, and NOT the NFC tester (`screen_settings.cpp::showReader`). This one answers "what is this spool"; the tester answers "what is on this chip", field by field, and keeps every id and the raw pages. Adding a field here is a decision about the first question, not a free addition. |
| `tigertag_cloud.cpp`, presence | The device's own document in the account, `users/{uid}/tigerspools/{mac}`. The identity, liveness and power field NAMES are shared with the TigerScale on purpose - Studio renders both from one template - so they are not renamed for local taste. `docs/PRESENCE.md` is the contract, including the Firestore rule the account needs before any of it is allowed. The document id is the Wi-Fi MAC and its format is frozen. |
| Anything that loads a screen outside the state machine | Every screen keeps an "already showing, do not rebuild" flag. Code that swaps screens out of band — the screenshot preview route does — must invalidate all of them, or each guarded screen believes it is still displayed and stops redrawing. The device then looks frozen while the web server answers normally. |
| `webcfg.cpp`, and the web server generally | The screenshot handler renders a preview screen, forces a repaint, and reads the `canvas` sprite. It is **not** on the same thread as the drawing any more - the interface has its own task (`lvgl_port`) - so every one of those touches `lvgl_port::Lock` first. The rule that replaced "same loop, therefore safe": anything outside the drawing task that calls into LVGL, or reads what LVGL paints, takes that lock. Miss one and the fault is a torn screenshot on a good day and a corrupted object tree on a bad one. |

### State, storage and the account

| Where | What you need to know |
|---|---|
| NVS printer keys, `main.cpp` | Keys are positional - `p{i}t/n/h/s/c/d/u/m/k/v/a`, eleven per printer - but **a printer is recognised by what it is, not where it sits**: `samePrinter()` in `tigertag_cloud.cpp` (type, serial with FlashForge's optional `SN` dropped, then address or mode). The import matches every printer to its stored entry that way and moves what the device owns - the switch `v`, a discovered host - with it. Anything else that reads or writes `p{i}*` must not assume position `i` is still the same machine after a sync; `printerIdx` is remapped by the import for that reason. `main.cpp` links notice a change of settings under them by `cfgSig()` and reconnect. |
| Wi-Fi association, `main.cpp` | **Never call `WiFi.begin()` directly** for the home network - call `staBegin()`. The driver's default scan stops at the first access point with the right name and caches that radio for good, so on a multi-AP network the device stays on whichever it heard first: measured at -79 dBm with the same network at -46 one room away. `staBegin()` erases the cached association and connects by signal; the setup portal's join sets the same scan and sort without erasing (the phone is on the device's own AP). `/api/scan?all=1` lists every radio the device hears, with BSSID and channel. |
| Account sync, `tigertag_cloud.cpp` | **The account owns** a printer's name, serial, access code and Anycubic fields; an empty account field keeps what the device had. **The host is shared:** LAN discovery (`reconcile()` in `main.cpp`) may correct a K2's address, and that correction stands only while the account keeps giving the address it gave last time - `p{i}a` remembers it. When the account says something new, it wins. Two documents for one printer are merged, newer `updatedAt` first (integer or Firestore timestamp; unreadable counts as oldest). A printer new to the device arrives switched off. |
| The two FreeRTOS tasks | `ttSync` (16 KB) and `ttPair` (12 KB) are the only threads in an otherwise single-loop firmware. They signal completion through bare `volatile bool`, and **there is no mutex anywhere in `firmware/src/`**. The sync task writes the `tigerspool` NVS namespace while the UI loop reads it through `loadCfg()`. Nothing serialises that. `loadCfg()` reads six string keys per printer in sequence, so a sync landing between two of them yields a printer whose host came from the new import and whose name came from the old — a row on the home screen that matches no printer that exists. **Open bug**, not an accepted design: [2026-09-03](docs/reviews/2026-09-03-concurrency-and-identity.md). |
| Factory reset, `main.cpp` | It must clear **all four** NVS namespaces, current and legacy: clearing only the current one leaves the legacy data, and the migration path restores the user's whole configuration on the next boot — a factory reset that quietly undoes itself. The list of four is written out **twice**, in `main.cpp` and in `webcfg.cpp`, with nothing tying them together. Add a namespace to one and the other reset silently stops being a reset. |
| The Firestore fetch, `tigertag_cloud.cpp` | The server-side `mask.fieldPaths` and the client-side `Filter` + `NestingLimit(40)` look redundant and are **independent**: the mask cuts bytes, the filter cuts nesting depth. Each is explained in a comment beside itself, forty lines from the other, so removing one because "we already filter" fails the other way — as `TooDeep`, or as a 47 KB body for one brand. |
| Every HTTPS call | All of them use `setInsecure()`: sign-in, refresh, pairing, Firestore. No certificate is verified anywhere, so anyone on the local network can read the TigerTag refresh token and the account credentials off the wire. Acceptable on a bench, and a release blocker. |

### Build and release

| Where | What you need to know |
|---|---|
| `platformio.ini`, flash settings | `memory_type` and `flash_mode` are a **per-board** fact, not a house rule. A sibling project mandating different values for a different board is not a precedent to copy: the wrong pair here produces a boot loop, or a board that never finds its PSRAM and dies in the first LVGL allocation. |
| Release assets, `boot_app0.bin` | Shipped by the Arduino core, not built here, and its path inside the package tree is not ours to depend on. Locate it; never hard-code it. A release that omits it produces a device that boots the wrong slot after its first OTA. |
| The documentation guards | They live inline in `.github/workflows/build.yml`, not in `scripts/`, so they cannot be run locally today. The GPIO6/7 one fires when a pin number and a signal name land on the same line: it cannot tell a wiring instruction from a description of itself, and has already failed on a document explaining what it checks. It also passes silently on an empty input set, and greps untracked build directories. A guard that cannot fail, or that fails on something correct, is one people learn to bypass. |

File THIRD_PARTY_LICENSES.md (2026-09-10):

# Third-party licenses

TigerSpool RFID is MIT-licensed ([LICENSE](LICENSE)). It builds on third-party
components that keep their own licenses.

> This page is kept in step with `lib_deps` in `firmware/platformio.ini` by
> hand. Nothing checks yet that the two agree - CI should, and does not.

## Dependencies

| Component | License | Used for |
|---|---|---|
| [arduino-esp32](https://github.com/espressif/arduino-esp32) | LGPL-2.1 | Framework: Wi-Fi, NVS, web server, DNS, mDNS, TLS, OTA |
| [ESP-IDF](https://github.com/espressif/esp-idf) | Apache-2.0 | Underlying SDK |
| [LovyanGFX](https://github.com/lovyan03/LovyanGFX) | FreeBSD (2-clause BSD) | Display and touch driver |
| [LVGL](https://github.com/lvgl/lvgl) | MIT | UI toolkit: every screen |
| [ArduinoJson](https://github.com/bblanchon/ArduinoJson) | MIT | Parsing printer reports, building commands |
| [WebSockets](https://github.com/Links2004/arduinoWebSockets) | LGPL-2.1 | Creality and Snapmaker transports |
| [PubSubClient](https://github.com/knolleary/pubsubclient) | MIT | MQTT transport: Bambu Lab, Elegoo, Anycubic |
| [PN532 / PN532_HSU](https://github.com/Seeed-Studio/PN532) (Seeed / elechouse) | Apache-2.0 | NFC reader driver — **vendored and patched**, see below |
| [ESP Web Tools](https://github.com/esphome/esp-web-tools) | Apache-2.0 | Browser installer |
| [mbedTLS](https://github.com/Mbed-TLS/mbedtls) | Apache-2.0 | TLS, bundled with ESP-IDF |
| [Font Awesome Free](https://fontawesome.com) | Fonts under SIL OFL 1.1, icon artwork under CC BY 4.0 | Every `LV_SYMBOL_*` glyph, plus the sun on the Display row, extracted into the `firmware/src/ui/font_ui_*.c` faces by `scripts/make-ui-font.sh`. The outlines come from the copy shipped inside the pinned LVGL package, so the library version pins them; no font file is committed. `lv_font_conv` extracts outlines from the font, so it is the OFL that governs what is compiled in. |
| [Montserrat](https://github.com/JulietaUla/Montserrat) | SIL OFL 1.1 | The UI typeface. Latin-1 and Latin Extended-A subsets extracted into `firmware/src/ui/font_ui_*.c` by `scripts/make-ui-font.sh`: the Medium weight from the copy shipped inside the pinned LVGL package, SemiBold from the typeface's own repository, cached outside the tree. No font file is committed. |
| [JetBrains Mono](https://github.com/JetBrains/JetBrainsMono) | SIL OFL 1.1 | The NFC tester's page dump, which has to line up in columns a proportional face cannot give. Eighteen glyphs - space, 0-9, A-F and x - extracted into `firmware/src/ui/font_ui_mono_16.c` by `scripts/make-ui-font.sh`, fetched from the project's own repository and cached outside the tree. No font file is committed. |

## The vendored PN532 driver

`firmware/lib/PN532/` will contain a **modified copy** of the Seeed/elechouse
PN532 library, kept in-tree rather than pulled from the registry.

**Why it is vendored:** the driver needs patches that are specific to this
hardware and cannot be applied to an upstream dependency — most importantly, a
wake-up preamble before every command, without which these modules answer once
after boot and then never again. See
[docs/MIGRATION.md](docs/MIGRATION.md#the-vendored-pn532-library).

**Obligations:** it is Apache-2.0. The upstream copyright notice, license text
and `NOTICE` are preserved in the vendored directory, and the modifications are
marked as such. Its own README will state clearly that it is modified, what was
changed, and why.

## LGPL components

Two dependencies are LGPL-2.1 (arduino-esp32 and the WebSockets
library). They are statically linked into the firmware image, which the LGPL
permits provided the user can relink against a modified version of the library.

That is satisfied here in the strongest way available: **the entire build is open
source.** The firmware source, the exact dependency versions and the build
configuration are in this repository, and CI reproduces the published binaries
from them. Anyone can substitute a modified library and rebuild.

## Trademarks

The **TigerTag** and **TigerSpool** names and logos are trademarks of the
TigerTag Project and are not covered by the MIT license. See
[TRADEMARK.md](TRADEMARK.md).

Bambu Lab, Creality, FlashForge, Snapmaker, Elegoo and Anycubic are trademarks of
their respective owners. TigerSpool is not affiliated with, endorsed by, or
sponsored by any of them. Their printer protocols are supported through
independent reverse-engineering, and their names are used only to state which
printers this project works with.

## Corrections

If a license here is wrong, or a component is missing, open an issue — we will
fix it.

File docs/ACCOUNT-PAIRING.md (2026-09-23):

# Linking a TigerTag account

How a device with no keyboard gets signed in — and why that sign-in is what makes
the whole product work.

---

## Why the device signs in at all

Because this is where TigerSpool stops being another spool scanner.

Your printers are already in your TigerTag account: you added them in
**[Tiger Studio](https://github.com/TigerTag-Project/TigerTag-Studio-Manager)**,
on a computer, with a keyboard, once. Names, addresses, serial numbers, access
codes.

When TigerSpool signs into that account it reads `users/{uid}/printers/*` and
configures itself. **The user never types a printer's IP address or access code
into a 2.0" touchscreen, because they never have to type it at all.** Add a
printer to your account next month and TigerSpool picks it up on its own, on its
next sync.

The account is not a nice-to-have wrapped around a local product. It is the
product's core, and the architecture assumes it.

---

## Two ways in, both without a device keyboard

Same as [TigerScale](https://github.com/TigerTag-Project/Tiger-Scale-V3). Users
arrive with accounts created either way, so both paths stay.

### 1. Email and password — typed on the phone

Reached from the configuration web page, at `http://tigerspool-xxxx.local` on the LAN
or through the setup portal. The user types their email and password **on their
phone's keyboard**, with their password manager available, on a page the device
serves.

The device exchanges them for a session and stores the refresh token. It never
stores the password.

Once signed in, the same address is the account page: the account's picture,
name and address, the printers with their on/off switches, a sync, and the
sign-out. The sync runs on the device's own sync task, never inside the web
request - see the `webcfg.cpp` row in [CODEMAP.md](../CODEMAP.md).

### 2. Google — a QR code on the device screen

Accounts created with Google have **no password to type**, so there is nothing a
form can ask for. These sign in by scanning a QR code shown on the device itself.

---

## The QR pairing flow

```
  TigerSpool                    TigerTag cloud                  owner's phone
      |                                |                              |
      |--- POST pair/start ----------->|                              |
      |<-- code + verify_url + poll_token                             |
      |                                |                              |
  [ draws a QR of verify_url ]         |        <---- scans it -------|
  [ prints the code beneath it ]       |                              |
      |                                |<--- opens verify_url --------|
      |                                |     (signs in with Google
      |                                |      if not already)
      |                                |<--- approves ----------------|
      |                                |  [ mints a custom token ]    |
      |                                |                              |
      |--- POST pair/poll ------------>|                              |
      |<-- status: approved, custom_token                             |
      |                                |                              |
      |--- signInWithCustomToken ----->|  (Identity Toolkit)          |
      |<-- idToken + refreshToken                                     |
      |                                |                              |
  [ stores the refresh token, reads the account's printers ]
```

**The URL in the QR already carries the code.** The user scans something that is
physically in front of them and taps approve on a phone where they are usually
already signed in. Nothing is read off one screen and typed into another.

### Why not RFC 8628

[RFC 8628](https://datatracker.ietf.org/doc/html/rfc8628) is the OAuth device
authorization grant, and it exists for exactly this shape of device. It was
examined and rejected — the same conclusion, for the same reasons, as
[TigerScale V3](https://github.com/TigerTag-Project/Tiger-Scale-V3/blob/main/docs/ACCOUNT-PAIRING.md):

- **The QR cannot carry the code.** Google's device-code response has no
  `verification_uri_complete`. It returns a bare URL and an eight-character code
  the user must retype. The best achievable experience becomes "scan this, then
  copy a code across from a screen 40 cm away" — which is the friction this whole
  design exists to remove.
- **Polling requires a `client_secret`**, which a public firmware binary must not
  carry. It could be provisioned at runtime, but that is machinery in service of
  a flow that is worse anyway.
- **It authenticates against Google only.** Apple, or any provider added later,
  would each need a separate path.

Pairing through TigerTag's own cloud has none of those properties, because both
ends belong to the project.

### Why the code and the poll token are different secrets

The **code** is short because a human may read it aloud or type it. The **poll
token** is long because whoever holds it receives the credential.

If one value did both jobs, anyone who glimpsed the screen from across the room
could poll for the token themselves. They are separate on purpose.

### What the approval page must show

The page reached by the QR has to name **which device is asking** — its name and
the last four of its MAC address — and **which account** it would be linked to.

The risk of a user approving someone else's pairing code is low here, because
they are looking at the physical screen the QR came from. But a page that says
only "Approve?" trains people to approve anything, and that habit is the actual
vulnerability.

---

## On-device screens

| Screen | Shows |
|---|---|
| **Account** | Signed-in email, or an invitation to link an account. |
| **Pairing** | The QR code, large. Under it the address from `verify_url` - scheme, query and code stripped off, drawn at the largest face that fits it on one line - then the short code, then a countdown to expiry. Nothing here is written into the firmware: change `verify_url` and the screen follows. |
| **Approved** | Confirmation and the account's email, then straight to importing printers. |
| **Denied** | Says so, and offers a fresh code. Never a bare error. |
| **Expired** | No screen: the countdown runs out and the device returns to the sign-in choice on its own. Ten minutes of nobody approving is not a failure to report, and choosing Google again fetches a fresh code. |

The pairing flow **must be reachable from the device screen**, not only from the
web page. A user standing in front of the box with a phone in their hand should
not have to find a URL on another device first.

---

## Endpoints

These are the endpoints **TigerScale V3 actually calls in shipped firmware**, and
the prototype calls the same ones. They are the deployed, working surface.

| | |
|---|---|
| Start | `POST https://us-central1-tigertag-connect.cloudfunctions.net/pairStart` |
| Poll | `POST https://us-central1-tigertag-connect.cloudfunctions.net/pairPoll` |
| Sign in | `POST https://identitytoolkit.googleapis.com/v1/accounts:signInWithCustomToken` |
| Refresh | `POST https://securetoken.googleapis.com/v1/token` |
| Printers | Firestore REST, `users/{uid}/printers/*` |

> **On `/api/device/pair/*`.** TigerScale V3's own documentation describes a
> first-party API path rather than raw Cloud Function URLs. Its firmware does not
> use it — the shipped code hardcodes the two Cloud Function URLs above. Treat
> `/api/device/pair/*` as an intended future surface, not something to code
> against today. If it is ever built, moving to it is a two-constant change.

### `pair/start`

Unauthenticated: the device has no identity yet. That is what the rate limit and
the short expiry are for.

Request:

```json
{ "device": "tigerspool-a1b2", "model": "TigerSpool RFID", "kind": "bridge", "fw": "1.0.0" }
```

Response:

```json
{
  "code":       "K7QF-3M2P",
  "verify_url": "https://tigersystem.io/pair/K7QF-3M2P",
  "poll_token": "<32 bytes, base64url>",
  "expires_in": 600,
  "interval":   5
}
```

### `pair/poll`

```json
{ "poll_token": "<the value from start>" }
```

| Response | Meaning |
|---|---|
| `{"status":"pending"}` | Nobody has approved yet. Poll again after `interval` seconds. |
| `{"status":"approved","custom_token":"<jwt>","email":"…"}` | Sign in with it. Single use — the record is consumed. |
| `{"status":"denied"}` | The owner refused. Stop and say so on screen. |
| `{"status":"expired"}` | Older than `expires_in`. Start again with a fresh code. The device does not wait for this: it stops polling and leaves the screen when its own countdown reaches zero. |

### Requirements on the cloud side

- Rate-limit `start` per IP and `poll` per token; reject a poll faster than
  `interval` with the same back-off the OAuth device flow uses.
- Codes are single-use and expire in ten minutes - the same ten the device
  counts down on screen.
- `verify_url` is what the QR carries and what the screen prints, so it must be
  an address a person can also type. `https://tigersystem.io/pair/<CODE>` and
  `https://tigertag-cdn.web.app/pair.html?c=<CODE>` both answer today; the
  device strips the code either way and prints the address alone.
- Store the pending record keyed by a **hash** of the poll token, not the token.

---

## Importing printers

Once signed in, the device reads the account's printers and writes them to NVS
as `p0`, `p1`, … - up to `MAX_PRINTERS`, 24.

**What it can reach.** Printers on the LAN are imported, and so are Bambu Lab
printers in cloud mode, read-only: the device reads their slots through Bambu's
broker but cannot write to them. A cloud-only printer of any other brand is
skipped, with the reason in the log, rather than imported as if it were on the
network.

**Sync is periodic and non-blocking.** The account is re-read every few minutes
on a background task, whatever screen is up. The result is applied only on the
printer screens - never mid-scan, and never under the slot grid someone is
using.

**The account is the source of truth for what it holds.** Name, serial, access
code and address are taken from the account at every sync, so a printer that
moves or gets a new code in Tiger Studio is followed. Two exceptions, both
deliberate: a field the account leaves empty keeps the device's value rather
than being blanked, and a K2 address found by LAN discovery stands while the
account keeps giving the address it gave before. What the account does not
hold - which printers are switched on - belongs to the device.

**A printer is recognised by its serial, not its position.** Adding or removing
a printer in the account does not hand anyone else's address, code or switch to
the printers after it, and two documents for one printer are merged, the newer
winning. The rules are `samePrinter()` in `tigertag_cloud.cpp`.

---

## Security

**The refresh token is a long-lived credential to someone's account.** It is
stored in **encrypted NVS**, never in plaintext flash. See [SECURITY.md](../SECURITY.md).

**TLS certificates must be validated.** The prototype disables verification on
every HTTPS call, which was acceptable on a bench and is not acceptable shipped.
A pinned root CA bundle, and a plan for rotating it, is required before release.
This is tracked as a release blocker.

**Signing out must actually revoke.** "Forget this device" has to clear the local
session *and* be reflected in the account, so that a user who sells or loses a
device can cut it off from a phone. A local-only wipe is not a revocation.

**The device never signs in to a printer vendor's cloud.** Where a vendor session
is needed — Bambu Lab's, for instance — Tiger Studio obtains it and the account
carries it. The firmware only consumes it.

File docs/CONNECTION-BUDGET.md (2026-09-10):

# The connection budget

How many printers one TigerSpool can hold open at once, how that is decided,
and every measurement it rests on. Written to be come back to: when a new brand
is added, when a number looks wrong, or when the budget is tuned per use case.

The code is [`firmware/src/printer_budget.h`](../firmware/src/printer_budget.h).
If this document and that file ever disagree, the file is what runs - fix
whichever is wrong, in the same change.

---

## The idea: load slots, like seats on a bus

The limit was never a **number** of printers. It is **internal RAM**, and how
much of it a printer's connection takes depends almost entirely on one thing:
whether it speaks TLS. A Bambu or an Anycubic costs 40-48 KB; everything else
costs 2-6 KB. Ten Elegoos fit where three Bambus do not, so a limit written as
"N printers" would be wrong for nearly every account.

So every printer takes the **load slots** its connection actually costs, and
the device has a fixed number of them. **One load slot is one kilobyte of
internal RAM.**

> **"Load slot", never plain "slot".** In this codebase a *slot* is a place a
> spool sits - an AMS tray, a station bay (`SlotState`, `slotCount`). The two
> must not be confused in code, in logs or in conversation.

A printer is refused at the moment somebody **switches it on**, when they can
see why - not later, as a dot that stays red with no explanation.

---

## The numbers

### The budget: 160 load slots

| | |
|---|---|
| Internal RAM free at boot, before any printer | **198 - 203 KB** (varies between boots) |
| Survival floor - below this the device closes a link to stay alive | **32 KB** |
| Usable for printers | **~166 KB** |
| **Budget** | **160 load slots** |
| Reserve kept for what the model does not count | **~6 KB** |

The reserve covers what the budget does not model: a web page being served, a
JSON document being parsed, a screen being built.

**Why 160 and not 200.** 200 is roughly what is free before anything runs, but
the device cannot spend all of it: 32 KB is the survival floor below which
`main.cpp` starts closing background links, and a few more are needed for the
device's own work. That leaves ~166.

**Why 160 and not 166.** It was 150 at first, keeping a 16 KB reserve. It was
raised to 160 deliberately, trading ten kilobytes of that reserve for room for
one more printer - a LAN Bambu beside a full bench, or several light ones.

**Why the thin reserve is safe.** The budget is not what stops a crash. The
32 KB floor and the *sustained* low-memory closer in `main.cpp` are: if free
memory stays under the floor for three seconds, the last background link is
closed. At worst a peak costs a printer its connection for a moment. The budget
exists to make the choice visible and predictable, not to guard the heap.

### Load slots per printer

Each is the **worst cost measured** for that connection, rounded up to the next
kilobyte. The margin is not spread across the brands - it lives once, in the
reserve above.

| Printer | Measured (worst of 5 passes) | Load slots | What the cost is |
|---|---|---|---|
| **First Bambu Lab in cloud mode** | 48.5 KB | **50** | opens the TLS session every cloud Bambu on the account shares |
| **Each further Bambu Lab in cloud mode** | 3.6 KB | **4** | only subscribes to the shared session |
| **Bambu Lab in LAN mode** | *not measured* | **50** | its own broker, its own TLS session |
| **Anycubic** | 40.4 KB | **41** | TLS |
| **Creality** | 5.6 KB | **6** | WebSocket |
| **Snapmaker** | 4.9 KB | **5** | WebSocket |
| **Elegoo** | 2.5 KB | **3** | plain MQTT, no TLS |
| **FlashForge** | 2.0 KB | **2** | HTTP; nothing held between requests |

**The one assumption left: Bambu in LAN mode.** Both LAN Bambus on the bench
were switched off at every measurement. It is charged 50 because it opens
exactly what a cloud printer opens - the same TLS client against a broker - but
that is reasoning, not a reading. The first bench with one switched on should
replace it.

### Per connection, not per printer

Only the cloud Bambu depends on what else is open. Every Bambu in cloud mode on
one account talks to the same regional broker with the same credentials, so
they share **one** TLS session ([`bambu_cloud.cpp`](../firmware/src/bambu_cloud.cpp)):
the first pays for it, each further one is a subscription on it.

| Bench example | Load slots |
|---|---|
| Three cloud Bambus | 50 + 4 + 4 = **58** |
| The same three before the session was shared | ~141 KB measured |

Every other printer's cost is its own and does not depend on the others.

### Worked example: the bench account

| Printer | Load slots |
|---|---|
| Creality Ender-3 | 6 |
| Bambu A1 (first cloud) | 50 |
| Bambu X1C (further cloud) | 4 |
| Snapmaker U1 | 5 |
| Elegoo Centauri Carbon 2 | 3 |
| Anycubic Kobra X | 41 |
| **Total** | **109 of 160 - shown as 68%** |

Measured the same evening: those six printers took **103.2 KB**. The model is
6 KB on the cautious side for this set.

---

## What the user sees

A bar in **Settings > Printers** and on the first-boot **Choose printers**
screen, above the list, labelled **Load** with a **percentage** - "68%", not
"109 / 160". Load slots are how the device counts; a person needs to know how
full it is, and a percentage says that without knowing what the 160 is.

- The accent colour while there is room, **orange from 85%**.
- A switch that would overflow the budget **does not move**, the bar turns
  **red** and the label reads **"Not enough room"** for two and a half seconds.
- Switching a printer **off** is always allowed.

The raw counts are in the serial log, in the form
`[budget] '<printer>' refused: <total it would reach> of 160 load slots`.

---

## What the model does not see

**Fragmentation.** A new TLS session needs one contiguous piece of about 40 KB,
and after three TLS sessions the largest free block has been measured as low as
18 KB - while the total said there was plenty. The budget adds totals and does
not see that shape.

Today the two agree, by arithmetic rather than by design: 160 load slots caps
TLS sessions at three, which is also the ceiling observed. The cheapest four -
one cloud Bambu and three Anycubics - come to 173, over the budget before a
single light printer.

A **one-off** TLS request - an account sync, an update check - is kept possible
by a separate mechanism, the TLS stand-down in `main.cpp`: background links step
aside for the second or two the request needs and come straight back. The
budget does not provide for those.

**The link limit.** Independently of memory, the code holds at most ten
links (`MAX_LINKS` in `main.cpp`). A printer that is switched on but powered off
still holds one while it retries. With the shared cloud session, the bench
account reached **ten links with 133 KB still free** - for this account the
binding limit is now the link count, not the RAM.

---

## How the numbers were measured

`/api/memtest` on the device's web server. It closes every link, holds the
account sync off, and opens printers **one at a time**, reading internal RAM
and PSRAM after each one has been up for ten settled seconds. The report goes
to the serial console.

    http://<device>/api/memtest          the printers switched on
    http://<device>/api/memtest?all=1    every printer on the account

Why it had to be built: numbers taken in normal running were not facts about
any printer. Links opened in groups and an account sync allocated a TLS session
in the middle, so the per-link figures added up to 193 KB against 135 KB
measured on the whole.

**Why the MQTT buffers are not in the table.** This framework is compiled with
`CONFIG_SPIRAM_USE_MALLOC` and a 4 KB internal threshold, so every allocation
over 4 KB - the 50 KB Bambu receive buffer included - lands in PSRAM, of which
8 MB is idle. What stays in internal RAM is mbedTLS, pinned there by
`CONFIG_MBEDTLS_INTERNAL_MEM_ALLOC`. That is why a printer's cost is, to within
a few kilobytes, whether it speaks TLS.

Five passes, 2026-09-10, on one Waveshare ESP32-S3-Touch-LCD-2:

| Pass | Setup | Notes |
|---|---|---|
| 1 | per-printer sessions, active printers | the first clean numbers |
| 2 | per-printer sessions, whole account | three TLS sessions fit, a fourth did not |
| 3 | shared cloud session, active printers | second cloud Bambu 3.2 KB |
| 4 | shared cloud session, active printers | repeat, evening |
| 5 | shared cloud session, whole account | three cloud Bambus on one session; stopped on link slots, not RAM |

---

## When to revisit

- **A new brand**: measure it with `/api/memtest` and add its worst case to the
  table and to `loadSlotsFor()`. Do not estimate.
- **A LAN Bambu is switched on at the bench**: measure it and replace the
  assumed 50.
- **The framework is updated**: re-run all five passes. A change to the
  PSRAM malloc threshold or to where mbedTLS allocates changes every number.
- **Tuning per use case** - planned: the numbers here are the floor any tuning
  starts from.
- **More than three TLS printers are wanted**: see
  [ROADMAP.md](ROADMAP.md#more-tls-printers-at-once). The two ways past it are
  mbedTLS in PSRAM, or sharing more sessions.

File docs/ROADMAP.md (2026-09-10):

# Roadmap

What is deliberately not done yet, why, and what has to be decided before it
can be. Everything here is a decision that was taken, not a thing forgotten —
an item leaves this file by being built or by being ruled out, never by
quietly rotting.

Anything already broken lives in [reviews/](reviews/), not here.

---

## The account: a heartbeat

**The device never writes to the account.** It reads printers, the profile and
the display name; there is no write path at all. So nothing in Tiger Studio can
show which TigerSpools exist, which are switched on, or when one was last seen.

The TigerScale does this with a periodic `PATCH` of telemetry it alone knows —
battery, charging state, Wi-Fi signal, mDNS hostname — every 30 s with the
screen lit, every 5 min with it dark, and forced immediately on an event a
person causes and then watches.

**Deferred on purpose.** It is not urgent, and it is the piece most likely to
be built wrong in a hurry.

**Decide before writing the first line: who owns each field.** This is the
sibling project's strongest advice on the subject and the reason it has no
write conflicts at all — the scale never writes a field Tiger Studio owns. It
*reads* `displayName` and never writes it. Once two writers share one field, no
arbitration rule is a good one: not last-write-wins, not merge, not a timestamp.
Partition the fields first and the conflict never exists.

**Ask the TigerScale agent for the specifics when this is picked up:** exactly
what it writes, to which document path, on what cadence, what forces an
immediate write, and how a failed write is handled. Its answer to the previous
question is in `_internal/TIGERSCALE-CLOUD-ANSWERS.md` and covers the shape;
the exact field list and paths were not asked for and should be.

Known limit to inherit knowingly: the scale has **no offline queue**. A failed
write is lost and the next one carries current values. That is right for
telemetry, where the newest value replaces the last — and wrong for anything
that must not be lost. If a TigerSpool ever writes an event rather than a state
("this spool went to this printer"), it needs a queue, and a queue does not get
added afterwards without rethinking the rest.

## The account: being told about changes

Nothing tells the device that an account changed. It polls every five minutes,
and refreshes when the printer picker opens — which covers the moment that
matters.

**Blocked on a question the firmware cannot answer: who writes the signal, and
when?** Every mechanism — a Firestore command queue, a realtime-database node
streamed over SSE — is inert until something in the backend writes to it. Half
of this feature lives outside this repository.

Worth building only when a specific need is named that genuinely cannot wait
five minutes. The test: *which screen would somebody sit and watch, waiting for
this to change?* On a scale that is the weight, and it does not come from the
network. On a spool reader there is no such screen yet.

## Firmware signing

The update connection is verified against the root store, so a device knows who
it is talking to — but not who produced the image. See
[OTA.md](OTA.md) for the reasoning and the condition for changing it. The key
must never touch CI, which is the part that makes this more than an afternoon.

## Accented text in the five languages that are not French

Done for French, and the font no longer stands in the way of the rest. The UI
faces are generated by `scripts/make-ui-font.sh` over
`0x20-0x7F,0xA1-0x17F,0x2022`, which covers German, Spanish, Italian,
Portuguese and Polish as completely as it covers French - the translations for
those five are simply still written without their diacritics.

What is left is a translation pass, not a font problem, and it wants somebody
who reads the language. Restoring a diacritic in the wrong place is worse than
leaving it out: a missing accent reads as a device that could not draw one, a
wrong one reads as a device that does not know the language. Polish in
particular is not a job for a search and replace.

## Anycubic in cloud mode

The LAN backends for Elegoo and Anycubic are written. Cloud mode is not, and it
is a different job: a cloud-mode Anycubic opens no local port, so the only route
is Anycubic's own service with signed REST requests and a second broker, and the
signing secrets live inside the closed slicer binaries.

**It is blocked on a decision, not on work.** The device cannot sign those
requests and cannot obtain its own credentials, so the realistic shape is the
one Bambu's cloud path already uses here: Tiger Studio holds the session and the
account carries a token the device presents. What that token is, who refreshes
it and what happens when it expires all have to be settled before any firmware
is worth writing - the answer decides what the account stores.

See [PRINTER-COMPATIBILITY.md](PRINTER-COMPATIBILITY.md).

---

## More TLS printers at once

How many printers fit today, and every number behind that, is in
[CONNECTION-BUDGET.md](CONNECTION-BUDGET.md): the device refuses a printer that
would overflow a budget of 160 load slots, and a TLS printer takes 41-50 of
them. This entry is about raising that ceiling.

**Measured, and it overturns what this entry used to say.** It was titled
"Move the MQTT buffers to PSRAM" and proposed vendoring PubSubClient to do it.
They are already there. This framework is built with `CONFIG_SPIRAM_USE_MALLOC`
and `CONFIG_SPIRAM_MALLOC_ALWAYSINTERNAL 4096`, so every allocation over 4 KB -
the 50 KB Bambu buffer, the 16 KB Anycubic one - goes to PSRAM without being
asked. `/api/memtest` shows it directly: the buffer lands in the PSRAM column.

What sits in internal RAM is **mbedTLS**, which the same config pins there
(`CONFIG_MBEDTLS_INTERNAL_MEM_ALLOC`). `/api/memtest`, every link closed, the
account sync held off, printers opened one at a time and read after ten settled
seconds:

```
baseline, 0 links   free 202124   largest 61428
creality            3856  internal       0 psram
bambu (background) 43940  internal    8208 psram
bambu (on screen)  47756  internal   51216 psram
snapmaker           4884  internal       0 psram
elegoo              2128  internal    8208 psram
anycubic           39432  internal   16400 psram
done, 6 links       free  60128   largest 18420   psram 8.1 MB free
```

**So a printer costs one thing: whether it speaks TLS.** A WebSocket or plain
MQTT printer is 2 to 5 KB and ten of them fit comfortably. A TLS printer - Bambu,
Anycubic - is 40 to 48 KB, and the device holds about **three**. Not by total
memory alone: the largest free block falls from 61 KB to 18 KB across those
three, and a new TLS session needs one piece that size. Fragmentation is what
stops the fourth, and it stops it before the total would.

**The two ways past it, neither small:**

1. **Put mbedTLS in PSRAM.** `CONFIG_MBEDTLS_EXTERNAL_MEM_ALLOC`. It is an
   sdkconfig option, and the Arduino core here is precompiled with its sdkconfig
   fixed - so it means building Arduino as an ESP-IDF component, a change of
   build system. It would take TLS from 40 KB internal to near nothing and lift
   the limit to whatever the ten-link cap allows. PSRAM is slower, and a TLS
   handshake is CPU-bound, so connects would get slower; how much is a
   measurement to make, not a guess.
2. ~~**Share one TLS session between Bambu printers on the same cloud
   broker.**~~ **Built in 1.46.0** (`bambu_cloud.cpp`): every cloud Bambu on
   an account rides one session, routed by the serial in each report's topic,
   and a further one costs 3.6 KB instead of ~48. LAN-mode Bambus each have
   their own broker and cannot share, and neither can Anycubic, so option 1 is
   what remains for those.

**What this entry no longer proposes:** vendoring PubSubClient, shrinking the
Bambu buffer after connect, or sizing it by role for the sake of internal RAM.
All three would move PSRAM around, of which 8 MB is idle.

### The 24-AMS case is simpler than it looked

A Bambu can chain up to 24 AMS units - 96 trays plus the external spool. Rare.
It is not a memory problem, because the report buffer is in PSRAM and PSRAM is
not short. It is a data-model problem: `BMAX` is 17, labels run A to D, and a
report that size would exceed the 50 KB buffer and be dropped whole, so the
screen would show nothing rather than something wrong. The fix is a buffer
sized for it (in PSRAM, free) and a slot array sized from the topology the
first report describes - "A1" to "X4" is twenty-four letters, exactly the
alphabet's usable run.

The periodic pushall is gone (81 KB a minute for trays that had not moved), so
such a machine costs one large report at connect and 1.2 KB increments after.

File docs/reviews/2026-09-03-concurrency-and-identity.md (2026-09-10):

# Review — shared state and printer identity

**Date:** 2026-09-03
**Scope:** `firmware/src/main.cpp`, `firmware/src/tigertag_cloud.cpp` — the
boundary between the UI loop and the two background tasks, and how a printer is
identified in storage. Plus what the panel actually shows.
**Method:** read-only. Findings 1 and 2 were found while mapping the code, not
while looking for bugs. Finding 3 was found by flashing this branch and looking
at the panel over `/screen.bmp`.

Findings 1 and 2 are **deferred**, with reasons below. Finding 3 was deferred
and then fixed in the same cycle — the reason for deferring it did not survive
contact with the observation that it was guardable. They are recorded here rather
than in `CODEMAP.md` because a landmine row explains a hazard to the next agent
but does not track it — and a documented bug reads as an accepted one.

## Quick wins

None. Neither of these is an hour's work; that is why they are deferred rather
than done.

## Findings

### 1. Shared state crosses a task boundary with no serialisation — deferred

**Where:** `tigertag_cloud.cpp` (`ttSync`, `ttPair`), `main.cpp` (`loadCfg`).

**What breaks.** `ttSync` (16 KB stack) and `ttPair` (12 KB) are the only threads
in an otherwise single-loop firmware. They are pinned to core 1 at priority 1 and
signal completion through bare `volatile bool`. There is no mutex, semaphore or
critical section anywhere in `firmware/src/`.

`ttSync` writes the `tigerspool` NVS namespace. The UI loop reads that same
namespace through `loadCfg()`, which reads six string keys per printer
(`p{i}t`, `p{i}n`, `p{i}h`, `p{i}s`, `p{i}c`, `p{i}v`) in sequence, with no
atomicity across the six.

**Failure scenario.** The user is on the home screen when a scheduled sync lands
— it runs every five minutes, so this needs no unusual timing. `ttSync` rewrites
printer 2 from an account whose entry for that slot has changed. `loadCfg()` is
midway through printer 2: it has already read the old `p2n` and now reads the new
`p2h`. The home screen renders a printer whose name is the old machine and whose
address is the new one. Touching it sends filament to a printer the user did not
select. Nothing logs an error, because from each side nothing went wrong.

`volatile` orders nothing across cores and is not a memory barrier; it only stops
the compiler caching the read.

**Why deferred.** The fix is a design decision, not a patch. Either NVS access is
funnelled through one owner, or the tasks stop writing storage and hand a result
back for the loop to commit. Both change how the account import works, and
choosing between them is not a Phase 3 question.

### 2. A printer's identity is its array index — FIXED 2026-09-10, without a migration

> **What happened.** The failure scenario below happened on the bench: Tiger
> Studio added a second AD5X document, every Bambu after it moved down one
> position, and X1C Home (Lan) took the A1's address and access code - rc=5
> until the device was reflashed - while the AD5X kept an address it had left.
>
> **The fix keeps the positional keys** and changes how the import uses them:
> every imported printer is matched to the stored entry that is the same
> machine (`samePrinter()`: type, serial, then address or mode), wherever it
> sat, and the switch and a discovered host move with it; `printerIdx` follows
> its printer. The account now wins for everything it owns, and for the host
> whenever it gives a new one (`p{i}a` remembers the last). Links reconnect
> when their printer's settings change under them (`cfgSig()`). No storage
> migration: a device on the old layout is matched on its first sync. What
> stays open is finding 1, the unsynchronised NVS access.

**Where:** `main.cpp` — `loadCfg()`, `saveCfg` paths, `savePrinterVisible()`;
`tigertag_cloud.cpp` — the import merge.

**What breaks.** Every stored field is keyed by position: `p0h`, `p1h`, `p2h`.
There is no stable identifier — not the serial, not a UUID. The array slot *is*
the identity. Two consequences compound:

- The merge that preserves locally-corrected values is gated on
  `if (i < n && nt == ct)` — same index **and** same type. When the type at an
  index changes, name, host, serial and access code are all taken from the import
  wholesale.
- `visible` is never written by sync at all, so it stays attached to a slot
  rather than to a printer.

**Failure scenario.** A user with eight printers hides seven and keeps the
FlashForge at index 3. They then delete a Bambu from their TigerTag account in
Tiger Studio. The next sync returns seven printers; everything after the deleted
one shifts up by one. Index 3 is now a Creality. Its type differs, so the merge
overwrites the FlashForge's host and access code with the Creality's, and the
`visible` flag stays on slot 3 — which is now a different machine. The user's
hand-corrected address is gone and the wrong printer is the only one on screen.
No error is reported; the sync did what it was written to do.

**Why deferred (at the time).** Fixing it means introducing a stable key and a migration for
devices that already store the positional form, which is exactly the kind of
storage change that has to be settled deliberately. It is also entangled with
finding 1: both are about who owns the printer list.

### 3. Settings and home are half-translated on screen — FIXED

**Where:** `ui/screen_settings.cpp`, `ui/screen_home.cpp`.

**What breaks.** Some user-visible labels go through `i18n::T()` and others are
English string literals in the source. Counted per screen: settings has 10
translated and 15 hardcoded; home has 2 and 1; the setup flow, by contrast, has
19 and 4.

**Failure scenario.** No timing needed — it is on screen right now. On a device
set to French, the settings menu reads *Reglages / Imprimantes / Wi-Fi / Compte
/ **Screen** / **Language** / **Update** / **Restart** / **Factory reset***, and
the account screen offers **Sign out** under a French heading. The home screen
is titled **Printers**. A user who chose their language during setup is shown a
product that half-forgot.

Verified by looking at the panel over `/screen.bmp` after flashing this branch,
not inferred from the source.

**Fixed**, and guarded. Nineteen keys added across eight languages, and
twenty-five literals replaced. It was first deferred as product work, which was
the wrong call: unlike findings 1 and 2 it is not design work, and it is
*guardable*. `scripts/check-ui-translated.py` now fails when a string literal
carrying a word appears in a UI source outside the three contexts that never
reach the panel. Translating them fixed it once; the guard makes it not come
back.

Note what the guard's first shape would have missed: watching call sites alone
let through five of the fifteen, because the settings menu keeps its labels in a
table and hands the table to `frame::row`.

## Finding 2 has a deadline, and it is a release rather than a date

**Read this before assuming "deferred" means "later is fine".**

Three facts about this product stop being decisions the moment someone else's
device holds them. They are un-fixable after that, not merely expensive:

| Frozen by the first public release | Why it cannot be changed afterwards |
|---|---|
| The **partition table** | A device cannot install a new one over the air. Changing it means every user reflashes over USB, or is stranded. |
| The **OTA manifest key layout** | Units in the field parse the shape they left with. An old one coming back after months must still be able to read what it is served. |
| **Printer identity being an array index** (finding 2 above) | `p{i}t/n/h/s/c/v` is in NVS on a paired device right now. Fixing it later means a storage migration or a reset — and a reset means every user re-pairs. |

The first two are recorded in `docs/OTA.md`. The third is the one that gets
missed, because it reads as ordinary technical debt and is filed here as
deferred design work. It is the same class as the other two: **a data-model fact
that becomes permanent when it leaves the building.**

**They share one deadline, and the deadline is the first public release, not a
sprint boundary.** Nothing forces the date. The release does.

> **Annotation, 2026-09-10.** The deadline passed with finding 2 open - public
> releases shipped from 1.x - and the fix turned out not to need the storage
> change this section feared. The keys stayed positional; what changed is that
> the import recognises each printer by its serial and moves its stored
> settings with it. A device on the old layout is matched on its first sync
> after updating, so nobody re-pairs. See finding 2.

At v0.1.0, with nothing published, all three are still free.

**Finding 1 does not share this deadline.** A missing mutex is a bug that gets
worse with load and can be fixed in any later version without anyone re-pairing
anything. It is more urgent in one sense and less final in another. Do not treat
the two as one pile: shipping makes finding 2 permanent, and only makes finding 1
more common.

## Decisions recorded, so they are not re-litigated

### Mojibake has no guard, deliberately — for now

`check-file-format.py` covers CRLF, byte-order marks, invalid UTF-8, invisible
and bidirectional controls, and missing final newlines. **Mojibake is none of
those.** A double-encoded sequence like `Ã©` is valid, visible UTF-8 and passes
every one of those checks. Nothing in the nine guards covers it.

So the position is *uncovered*, not *covered*, and the earlier claim that the
format guard subsumed it was wrong.

It is still not being written today, on narrower grounds: this repository has
never had the incident, and a guard that can find nothing is ceremony that
teaches people to skim output. But the provenance is exactly the risk profile —
a Portuguese prototype, hand-translated in bulk, with at least one commit made
through a web editor rather than a client index. If a single `Ã` ever appears in
a diff, write the guard that day rather than fixing the one occurrence.

### Restoring accents is one unit of work per font, not per language

On-device strings are written without diacritics — "Francais", "Espanol",
"Changer de reseau". That is the font constraint being respected, not a defect,
and `check-ui-fonts.py` now enforces it.

Anyone tempted to "fix" one accent will ship a blank box. The work is:

1. Generate a Latin-1 subset font. That unlocks French, German, Spanish,
   Italian and both Portuguese variants **at once**.
2. Generate Latin Extended-A on top of it for Polish, which needs `ł ą ę ż ź ć`
   and which Latin-1 does not cover.

So it is two font builds, not eight translation passes, and no accent should be
restored before the font that carries it exists.

### The guards depended on `firmware/.pio` — fixed

`scripts/font_range.py` reads the compiled font's real character range from
LVGL's generated font source, which lives under `firmware/.pio/libdeps`. It
raises rather than guessing when that is absent — correct, because a validator
that assumes a range accepts exactly the characters it exists to reject.

The cost is that `verify.sh --quick`, and therefore the pre-commit hook, cannot
run in a fresh clone until someone runs `pio pkg install`. A hook that does not
work out of the box is a hook that gets uninstalled.

**Done.** `scripts/gen-font-range.py` extracts the range into
`scripts/font_range.json`, registered with `scripts/check-generated.py` so CI
re-derives it from the LVGL source on every push. `check-ui-fonts.py` reads the
committed fact. A fresh clone now runs all nine guards green and names the one
item it could not re-derive. Third application of the same shape, after the
reference header and the device names.

## What was not looked at

- The four printer backends, beyond the interface they share.
- The LVGL screens, except where they read state.
- The captive portal and the legacy web page.
- The reader and the NFC decode path.
- Findings 1 and 2 on hardware. Both are read from the source; neither has been
  reproduced on a device, and the timing of finding 1 in particular has not been
  measured. Finding 3 was seen on the panel.
- The scan and result screens with a real tag. The two brand names whose
  no-break space was removed this cycle cannot be confirmed on screen without a
  Duramic 3D or Filament PM spool in front of the reader.

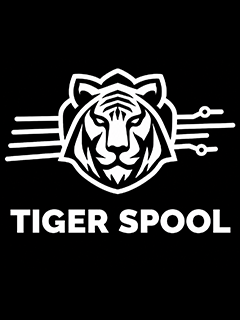
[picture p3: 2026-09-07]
assets/TigerSpoolRFID-BootScreen.png

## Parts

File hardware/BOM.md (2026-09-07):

# Bill of materials

Everything needed to build one TigerSpool. **The electronics are identical for
every printer brand** — only the printed shell changes ([models/](../models/)).

> **Prices are indicative** and were not re-checked at the time of writing.
>
> Some links here are Amazon affiliate links: buying through them pays the
> project a small commission at no cost to you. Nothing on this list is chosen
> because it is affiliated — the parts came first, and any equivalent module
> works. Where a link is missing, the part is named precisely enough to search
> for.

## Three things to buy

| # | Part | Why this one | ~Price |
|---|---|---|---|
| 1 | **[Waveshare ESP32-S3 2inch Capacitive Touch Display Development Board](https://link.amazon/B0c5hr3uf)** — 240×320 IPS, LX7 dual-core to 240 MHz, Wi-Fi and Bluetooth. (Listed with an OV5640 camera header; the camera is not included and TigerSpool does not use it.) | 2.0" 240×320 IPS with CST816S capacitive touch, ESP32-S3**R8**, 16 MB flash, 8 MB octal PSRAM. The screen, the touch panel and the MCU are one board — there is no separate display to wire. The 16 MB is what makes two OTA slots comfortable. | ~25 € |
| 2 | **PN532 NFC module**, V3 breakout with DIP switches — e.g. [this two-pack](https://link.amazon/B0dyEfwKa) | Reads the NTAG21x chips TigerTag uses. It **must** support **HSU/UART** mode; the DIP-switch V3 boards do, and both switches go to `0` / OFF. A two-pack costs barely more than one, and the spare settles "is it the module or my wiring?" in a minute. | ~9 € the pair |
| 3 | **A USB-A to USB-C cable that carries data** — e.g. [this one](https://link.amazon/B00Xg3WT4) | Powers the board and flashes it. **Speed is irrelevant**: the ESP32-S3's native USB is full-speed, so any USB 2.0 data cable is enough. What matters is that it carries data at all. | ~5-10 € |

Plus a **3D-printed case** from [models/](../models/), about 30 g of filament.

**The four jumper wires come with the PN532** — 3V3, GND, TX and RX, and that is
the whole harness. There is nothing else to order.

**Indicative total: ~40 €** plus filament.

> **The cable is not a detail.** Plenty of USB-C cables carry power and nothing
> else — the ones bundled with phone chargers usually do. With a charge-only
> cable the board lights up, the screen works, and no computer ever sees a serial
> port: the web installer finds nothing to install to and `scripts/flash.sh`
> reports no device. It reads exactly like a dead board. If a cable you know
> transfers files works, use that one.

## What is deliberately not on this list

**No separate display, no microcontroller board, no touch controller.** The
Waveshare board is all three. It costs more than a bare ESP32-S3 and removes the
entire class of display wiring problems, which on a product aimed at
non-technical users is the right trade.

**No level shifters.** The PN532 runs at 3V3 — the same as the ESP32-S3. Do not
power it from 5 V. See [../docs/WIRING.md](../docs/WIRING.md).

**No battery.** TigerSpool sits next to a printer that is already plugged in.

## The tags

TigerSpool reads **TigerTag** NFC chips, which are not included:

- **TigerTag store** — <https://tigertag.io>
- Filament from partner brands ships with them already attached.

The tag protocol is open and documented:
[TigerTag-RFID-Guide](https://github.com/TigerTag-Project/TigerTag-RFID-Guide).

## Board variants — read this before ordering

**Waveshare sells several similar boards.** `ESP32-S3-Touch-LCD-2` is a 2.0"
240×320 panel. The 1.28", 1.69" and 3.5" boards in the same family have different
panel controllers and different pin assignments, and this firmware will not run
on them correctly. Check the silkscreen, not the listing title.

**PN532 clones vary.** The DIP switch mode table is silkscreened on the module
itself and the mapping is not always the same between clones. Read your own
module rather than trusting a table found online — including the one in
[../docs/WIRING.md](../docs/WIRING.md).

## Assembly

1. Wire the PN532 to the board exactly as in [../docs/WIRING.md](../docs/WIRING.md).
   **Four wires, two of them crossed.**
2. Set both DIP switches on the PN532 to `0` / OFF.
3. Flash the firmware from the browser — [../installer/](../installer/).
4. Verify the reader responds *before* closing the case: bring-up checklist in
   [../docs/WIRING.md](../docs/WIRING.md#bringing-a-new-build-up).
5. Mount the reader antenna away from the display's metal back and any ground
   plane. Read range is only 2–4 cm and both will eat it.
6. Close the case.

<!-- TODO(images): assembled build photo — docs/images/ -->

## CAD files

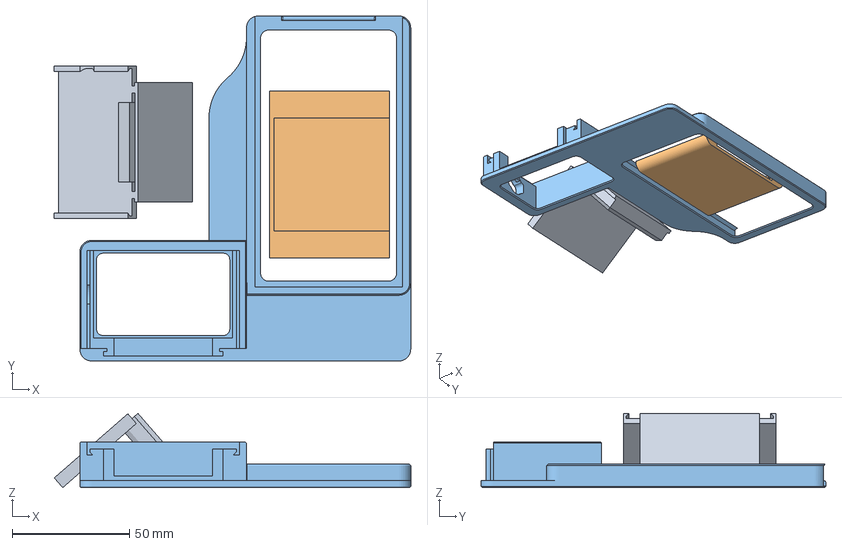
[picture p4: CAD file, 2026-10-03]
Model3D/4.FlashForge/Creator5-5Pro/BambuStudio/tigerspool-creator5-full.3mf
151.9 x 147.0 x 31.7 mm
RFID
TigerSpool_Flashforge-Creator-5-Pro_Cover_V5
TigerSpool_Flashforge-Creator-5-Pro_Frame_V5

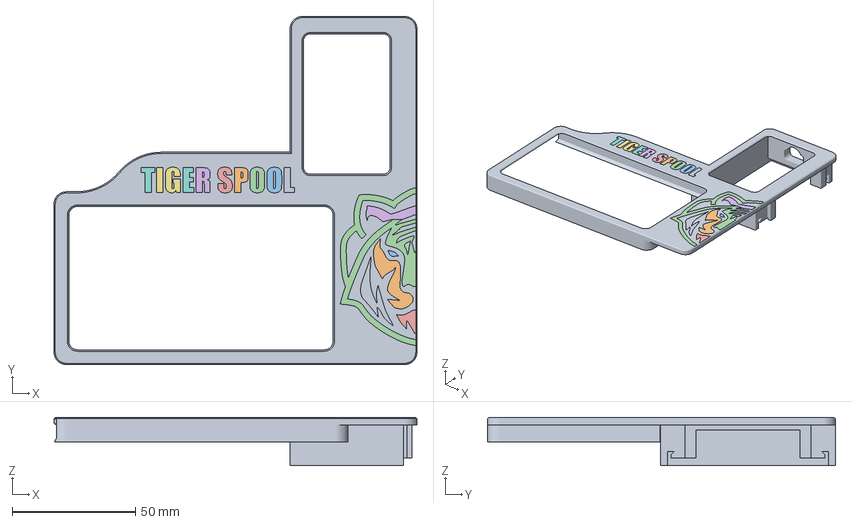
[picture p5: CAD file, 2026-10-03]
Model3D/4.FlashForge/Creator5-5Pro/OriginalFiles/tigerspool-creator5-frame.3mf
147.0 x 141.0 x 19.5 mm
Corps115
Corps116
Corps117
Corps118
Corps119
Corps120
Corps72
Corps73
Corps74
Corps75
Corps76
Corps77
Corps78
Corps79
Corps80
Corps81
Elec_box (1)

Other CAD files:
Model3D/4.FlashForge/Creator5-5Pro/FlashStudio/tigerspool-creator5-full.3mf
Model3D/4.FlashForge/Creator5-5Pro/Source/tigerspool-creator5.f3d

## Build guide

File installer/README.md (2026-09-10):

# Web installer

> **Status: live** at
> <https://tigertag-project.github.io/TigerSpool-RFID/>. `index.html` is the
> page; `manifest.json`, `version.json` and the four images are generated at
> release time by `scripts/make-manifest.py` and never committed.

Flash a TigerSpool from a browser. Plug the board into a computer, open the page,
click **Install**. No PlatformIO, no Arduino IDE, no command line, no drivers to
hunt down.

Built on [ESP Web Tools](https://esphome.github.io/esp-web-tools/), which speaks
WebSerial. **Chrome and Edge on a desktop OS only** — Safari and Firefox do not
implement WebSerial, and no mobile browser does. The page has to say so plainly
rather than failing silently.

## How it works

```
   browser                              GitHub Pages
      |                                      |
      |--- GET manifest.json --------------->|
      |<-- version + parts list              |
      |                                      |
      |--- GET the .bin files -------------->|
      |<== bootloader, partitions, app =====|
      |                                      |
  [ user picks the serial port ]             |
  [ esptool.js writes over WebSerial ]       |
  [ board reboots into TigerSpool ]          |
```

Published to GitHub Pages by CI on every tagged release. **Binaries are never
committed to this repository** — they are built by the release workflow and
deployed with the page, so the installer and the OTA channel always offer the same
build. See [../docs/OTA.md](../docs/OTA.md).

## `manifest.json`

Generated by CI (`scripts/make-manifest.py`) from the firmware's own version
macro, in the same run as the device's `version.json`. Never hand-edited —
hand-editing is how an installer and an OTA channel drift apart. What it
publishes today:

```json
{
  "name": "TigerSpool RFID",
  "version": "1.46.0",
  "new_install_prompt_erase": true,
  "builds": [
    {
      "chipFamily": "ESP32-S3",
      "parts": [
        { "path": "bootloader.bin", "offset": 0 },
        { "path": "partitions.bin", "offset": 32768 },
        { "path": "boot_app0.bin",  "offset": 57344 },
        { "path": "firmware.bin",   "offset": 65536 }
      ]
    }
  ]
}
```

> The offsets live once, in `OFFSETS` in `scripts/make-manifest.py`, and must
> match `firmware/partitions.csv`. There is no filesystem image: the device's
> web assets are compiled into the firmware.

## What the page must do

**Say what is happening.** Erasing, writing, verifying, done — with progress.
A blank page during a 60-second write is where users pull the cable.

**Name the failure.** "No serial port found" needs to lead to the two real
causes: a data-capable USB cable, and a browser that is not Chrome or Edge.

**Offer the same languages as the firmware.** A user who cannot read the installer
cannot use the device.

**Erase on first install, preserve on update.** `new_install_prompt_erase` is
there so a returning user does not silently lose their Wi-Fi and their account.

## Layout

```
installer/
├── index.html      the page, with the ESP Web Tools button
├── manifest.json   generated by CI
├── locales/        translations, matching the firmware's
└── firmware/       built by CI, deployed to Pages — NEVER committed
```

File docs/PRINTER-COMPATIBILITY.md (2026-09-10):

# Printer compatibility

**"Any printer" is the ambition. This page is the truth.**

Marketing gets one line on the front page; this table gets the rest. If a printer
is not on it, TigerSpool does not support it. If it is on it at 🧪, that means
someone has to do work before it does.

> **Status of this page:** everything marked 🟢 *proven* below was proven with
> this repository's firmware, on real printers. Nothing here is claimed on the
> basis of documentation alone.

---

## The three levels

| | Level | What it means for you |
|---|---|---|
| ✅ | **Automatic** | Add the printer once in Tiger Studio. TigerSpool finds it, connects, and works. Nothing to configure on the device. |
| ⚙️ | **One setup step** | Works, but the printer needs one thing switched on or read off its own screen — usually LAN mode, sometimes an access code. Once. |
| 🧪 | **Experimental** | Not finished. May be partly implemented, may be unimplemented, may be broken by a printer firmware update. Do not buy hardware for this. |

---

## Support matrix

| Brand | Models | Level | Transport | Prototype status | What's needed |
|---|---|---|---|---|---|
| **Creality** | K2, K2 Plus | ⚙️ | WebSocket `:9999` | 🟢 proven on hardware | **LAN mode must be on** in the printer's network settings, or port 9999 refuses connections. |
| **FlashForge** | Creator 5 / 5 Pro, **AD5X** | ⚙️ | HTTP `:8898` | 🟢 proven on hardware | Serial number **and check code**, both from the printer's network info screen. Imported automatically if the printer is in your TigerTag account. |
| **Bambu Lab** | A1, A1 mini, A2L | ⚙️ | MQTT/TLS `:8883` | 🟢 proven on hardware | **LAN mode on**, plus the serial and the 8-character access code from the printer screen. Imported automatically from your account. |
| **Snapmaker** | Artisan, J1, J1s, U1 | ⚙️ | Moonraker WebSocket `:7125` | 🟢 proven on hardware | Nothing — Moonraker needs no authentication on the LAN. The printer's IP is all it takes. |
| **Bambu Lab (cloud)** | X1, P1, and any printer not on your LAN | 🧪 | MQTT/TLS to Bambu's broker, one session shared by every cloud printer on the account | 🟢 **reading** proven on hardware (A1, X1C) · writing not supported | **Read only**: slots are shown, a tag cannot be written - Bambu's cloud does not take the command. Depends on a Bambu session token that **Tiger Studio** obtains and stores in your account; the device never signs in to Bambu itself. The token expires roughly every three months and has to be renewed in Studio. |
| **Elegoo** | Centauri Carbon 2 and others | ⚙️ | MQTT `:1883` (plain TCP) | 🟢 **reading** proven on hardware (Centauri Carbon 2) · writing not yet confirmed on a printer | Serial number and the MQTT password (an "Access Code" on the printer). Imported automatically from your account. |
| **Anycubic** | Kobra 3 V2, Kobra X, ACE units | ⚙️ | MQTT/TLS `:9883` | 🟢 **reading** proven on hardware (Kobra X) · writing not yet confirmed on a printer | **LAN mode**, and **the printer must be paired in AnycubicSlicerNext at least once** — its broker credentials exist nowhere else. Tiger Studio reads them from there into your account. |
| **Anycubic (cloud)** | any Anycubic not in LAN mode | 🧪 | signed REST + MQTT to Anycubic's cloud | 🔵 protocol documented, firmware not written | Nothing on the printer — but it is a **second, heavier code path** than LAN, and whether it belongs in v1 is undecided. |

**How many at once** depends on which: a Bambu or an Anycubic takes far more of
the device's memory than the others, so the limit is a load budget rather than a
count - see [CONNECTION-BUDGET.md](CONNECTION-BUDGET.md).

> **Anycubic TLS — the supposed blocker does not exist.** Tiger Studio's protocol
> notes say the broker must be pinned to TLS 1.2 because it requests an optional
> client certificate that a TLS 1.3 stack aborts on. Probed directly against a
> **Kobra X (modelId 20030)** in LAN mode, that is not what happens: the broker
> completes **both** TLS 1.3 (`TLS_AES_256_GCM_SHA384`) and TLS 1.2
> (`ECDHE-RSA-AES256-GCM-SHA384`), sends **no** certificate request at all, and
> accepts every mbedTLS-friendly suite tried — including
> `ECDHE-RSA-AES128-GCM-SHA256`, the ESP32's default. Its certificate is
> self-signed, as expected.
>
> This may vary by model or firmware, so it is recorded as an observation rather
> than a rule. But on this hardware the ESP32 will handshake, and the largest
> stated risk for the Anycubic backend is not present. The device's own mbedTLS
> has since completed it too.

**Legend for implementation status:** 🟢 implemented in this firmware and
verified against a physical printer · 🟡 implemented, not fully verified ·
🔵 protocol fully documented and proven on real hardware **elsewhere**
([Tiger Studio](https://github.com/TigerTag-Project/TigerTag-Studio-Manager)), but
no firmware backend written yet · 🔴 nothing at all.

---

## Elegoo and Anycubic

Both have a firmware backend, over the LAN, and both read slots on real
printers. Unlike every other protocol in this project, **neither had to be
reverse-engineered**: both were already documented and working in
[Tiger Studio](https://github.com/TigerTag-Project/TigerTag-Studio-Manager), from
live captures of the vendors' own slicers against real printers:

- `renderer/printers/elegoo/PROTOCOL.md`
- `renderer/printers/anycubic/PROTOCOL.md`

That turned support from open-ended research into a porting job.

### Proven from this repository, on Benoit's own printers

Both protocols were re-checked live on 2026-09-08, against a Centauri Carbon 2
at 192.168.40.102 and a Kobra X at 192.168.20.200, using exactly the topics and
payloads the firmware backends send:

| | Elegoo | Anycubic |
|---|---|---|
| Connect | `CONNACK rc=0` with user `elegoo` + access code | `CONNACK rc=0` over TLS 1.2, self-signed |
| Register | `{"error":"ok"}` | n/a |
| Read | `2005` → Canvas `connected:1`, four trays with brand, type, `#RRGGBB` | `getInfo` → `state:success code:200`, box **-1** with **four** slots |
| Shape | matches the backend's parser | matches the backend's parser |

So the transports, the credentials, the topics and the payload shapes are all
correct. The device then read both printers itself (1.36.0): the Centauri
Carbon 2's four trays and the Kobra X's four slots, the same the printers report
to Tiger Studio. The credentials the device seemed to lack - the Elegoo access
code, the Anycubic `username` and `acuModelId` - were in the account all along;
the import was discarding them.

**mbedTLS on the ESP32 completes the Anycubic handshake** - TLS 1.2,
self-signed, no client certificate. That was the biggest open question in the
protocol notes.

Not yet confirmed on a printer: **writing** a slot, on either brand. The
commands are the ones Tiger Studio sends (below), but a write has not been read
back from the printer after the device sent it.

### What is already known

| | Elegoo | Anycubic |
|---|---|---|
| Transport | MQTT over **plain TCP**, port 1883 | MQTT over **TLS**, port 9883, self-signed |
| Auth | broker username `elegoo` + password, plus the serial number | `deviceId` + username + password |
| Read slots | method `2005` (with Canvas) / `1061` (single extruder) | `getInfo` on the `multiColorBox` topic |
| Write a slot | method `2003` (Canvas) / `1055` (single extruder) | `setInfo` on the same topic |
| Colour | `#RRGGBB`, uppercase | `[r, g, b]` array |
| Materials | a captured 50-entry `filament_code` table keyed by type × name | ~30 accepted names, sent verbatim |
| Discovery | UDP broadcast, port 52700 | `GET http://<ip>:18910/info`, no auth |

Elegoo is in some ways **simpler than Bambu Lab** — no TLS at all.

### The two things that will bite

**Anycubic's TLS.** Tiger Studio's notes say the broker demands TLS 1.2 and
requests an optional client certificate that a TLS 1.3 stack aborts on. The Kobra
X did neither (see the note under the matrix), and the ESP32 handshakes with it.
Another model or firmware may still behave as the notes say.

**Anycubic credentials cannot be obtained from the printer.** The `/info`
endpoint does not expose them and they cannot be derived from what it does expose
— that was established exhaustively, not assumed. They exist only in
AnycubicSlicerNext's own config file, which Tiger Studio decodes on the desktop
and writes to your TigerTag account.

For TigerSpool that is not an obstacle, it is the product working as designed:
the desktop does the part that is impossible on a 2.0" screen, and the device
imports the result. But it means **an Anycubic printer must have been paired in
AnycubicSlicerNext at least once**, and the documentation has to say so plainly
rather than letting a user discover it as a failure.

### LAN is written. Cloud is not, and it is not the same job.

An Anycubic printer is reachable **either** over the LAN **or** through Anycubic's
cloud, and the account says which. The LAN backend exists now. A cloud-mode
printer keeps no open local ports at all: there is nothing on the network to
connect to, and the only route is Anycubic's own service — signed REST requests
against a second broker, with signing secrets that live inside the closed slicer
and app binaries.

That is not a variant of the LAN backend with a flag set. It is a second client
against a different service, and the device cannot obtain its own credentials for
it any more than it can for the LAN one. The realistic shape is the Bambu cloud
pattern already in this firmware: **Tiger Studio holds the session and the
account carries a token the device presents.** Nothing in the firmware can be
built until that is decided, because it determines what the account has to store.

Bambu Lab's cloud path is that pattern, and it is built: Tiger Studio holds the
session, the account carries the token, and the device reads slots with it.

### Still useful from the community

- **Other models.** The captures come from specific printers. A protocol that
  holds across a brand's range is worth far more than one that fits one machine.
- **Testing** on other models, and a confirmed slot write on each brand.

## Slot names

A slot name is what the user reads on the box and matches against the machine in
front of them. It has to be the name the printer's own interface uses, and the
same one Tiger Studio shows — a slot called something else here is a slot the
user has to translate in their head.

These are taken from Tiger Studio's renderers, which are the reference:

| Brand | External | Units |
|---|---|---|
| **Bambu Lab** | `Ext.` | `A1`–`A4` for the first AMS, `B1`–`B4` for the second, and so on |
| **Creality** | `Ext.` | `1A`–`1D` for the first CFS box, `2A`–`2D` for the second |
| **FlashForge** | `Ext.` | `1A`–`1D` for the material station. `T1`–`T4` are something else: the Creator 5 Pro's tool-changer nozzles, not station slots. |
| **Elegoo** | `Ext.` | `S1`–`S4` |
| **Snapmaker** | — | `E1`–`E4`, one per extruder |
| **Anycubic** | see below | `A1`–`A4`, `B1`–`B4`, … one row per ACE unit |

**There is one external slot per printer.** Not one per CFS, AMS or ACE unit —
one for the machine. It belongs to the printer, and it is drawn once. That is why
Tiger Studio puts `Ext.` on the first row and an invisible spacer in the same
column on every row after it: the grid stays aligned without inventing an
external spool that does not exist.

Both backends here follow it: the external slot is index 0, written once, before
any unit.

**The letter and the digit swap places between brands.** Bambu is
unit-then-position (`A1`), Creality is box-then-position (`1A`). They are not
typos.

**Reported slots are not loadable colours.** A Kobra X has four inputs in its
head. One feeds a splitter serving four ACE units — sixteen colours — and the
other three take one spool each, so the machine holds **nineteen** colours. Four
ACE units are sixteen slots, not twenty.

### Anycubic, and what is actually known

**The protocol does not describe the wiring, and a backend must not try to.** You
receive the list of ACE units. You do not learn which head input each one hangs
off, and you do not need to: the printer resolves a box and slot to a physical
path itself. Modelling the topology would be inventing a fact the machine never
sends.

What the hardware does, from the bench:

- A **Kobra X** has four inputs on the print head. Each takes one spool directly,
  or an ACE unit. So the same machine can be four direct colours, or sixteen
  through four ACE units, or a mix — and the report looks the same shape either
  way.
- A **Kobra S1** and **S1 Max** have a slot the machine calls **"Holder"**. That
  is the `Ext.` equivalent, one per printer, consistent with the rule above.

**What is not settled is how box `-1` should be labelled.** Tiger Studio's
renderer builds a per-slot prefix of `E` for box `-1`, giving `E1`–`E4` — four
external slots, against the one-per-printer rule. The header comment in that same
file says `[Ext.] [A1] [A2] …` instead. The two disagree inside one file, and the
Kobra X reports four slots on box `-1` while the S1's "Holder" is plainly one.

Decide it against a machine, not against the report. Everything else in this
table is settled.

Slot **names** are decoupled from slot **indices**: renaming is safe, adding a
slot changes the protocol mapping and is not.

## What "supported" does and does not mean

**It means:** TigerSpool can write a material name, a colour and nozzle/bed
temperatures into a numbered slot, and can read back what is currently in each
slot to show it on screen.

**It does not mean:**

- **Loading or unloading filament.** TigerSpool sets metadata. It does not drive
  the extruder. No supported printer exposes load/unload the way it exposes
  slot configuration.
- **Any colour you like.** FlashForge accepts only its own 24-colour palette;
  a tag's colour is snapped to the nearest one. Bambu Lab accepts exact RGB.
- **Any material name you like.** Each printer has a fixed vocabulary. Materials
  the printer does not know are mapped to the closest one it does.

> **What that looks like in practice.** A verified end-to-end assignment on a
> FlashForge AD5X: the tag said **PLA High Speed, R3D, `#DC123F`**; the printer
> ended up showing **PLA, `#F82D29`**. The colour was snapped to the palette's
> nearest entry and the "High Speed" variant was dropped, because those are the
> only values the printer accepts. Nothing failed — but the device must **say**
> the colour was adapted, or a user will read a correct result as a bug.
- **Working during a print.** Changing slot configuration mid-print is not
  supported and may be refused by the printer.

---

## Why a printer that "should work" may not

**Printer firmware updates.** Every protocol here except Snapmaker's is
reverse-engineered from a vendor's private API. Vendors change them without
notice and owe nobody compatibility. A printer that worked last month can stop.

**LAN mode.** Creality, FlashForge and Bambu Lab all gate their local APIs behind
a mode that is off by default. This is the single most common reason a correctly
configured printer shows as offline.

**Network segmentation.** Guest networks, VLANs and client isolation on the
access point will all prevent TigerSpool from reaching a printer that is
otherwise perfectly configured. They must be on the same network segment.

**Silent acknowledgements.** At least one printer answers "success" to commands it
did not understand. Where the protocol allows it, TigerSpool re-reads slot state
after writing to confirm the change actually landed — but confirmation is not
possible on every protocol.

---

## Adding a printer brand

The [architecture](ARCHITECTURE.md#printer-abstraction) is built so that a new
brand is one class implementing one interface, and touches nothing else. What
that class has to provide:

1. **Connect and stay connected** over whatever transport the printer speaks,
   recovering on its own when the network drops.
2. **Report slots** — how many, what they are called, and what is currently in
   each one.
3. **Accept an assignment** — translate a decoded TigerTag into the printer's own
   material vocabulary and colour constraints, and send it.
4. **Tell the truth about failure** — including detecting the case where the
   printer claims success and does nothing.

See [CONTRIBUTING.md](../CONTRIBUTING.md).

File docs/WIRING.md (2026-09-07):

# Wiring

Four wires. Getting two of them the wrong way round is the single most common way
to end up with a board that boots, shows a screen, and never reads a tag.

Everything on this page was verified on a bench prototype against real hardware.
Where something is *not* verified it says so.

---

## Bill of connections

**Board:** Waveshare ESP32-S3-Touch-LCD-2 — ESP32-S3**R8**, 16 MB flash, 8 MB
octal PSRAM, 2.0" 240×320 IPS with a CST816S capacitive touch panel.

**Reader:** PN532 module (the common red V3 breakout), in **HSU** mode.

### Wiring Diagram

> [!NOTE]
> Four wires. They come with the PN532 module, so there is nothing to buy.

<p align="center">
  <a href="https://app.cirkitdesigner.com/project/7a6c0887-8e44-4303-81b3-be51aab4b40a">
    Wiring diagram: PN532 to ESP32-S3-Touch-LCD-2 — VCC to 3V3, GND to GND, TXD to GPIO44, RXD to GPIO43
  </a>
</p>
<p align="center">
  <sub><a href="https://app.cirkitdesigner.com/project/7a6c0887-8e44-4303-81b3-be51aab4b40a">Interactive schematic in Cirkit Designer</a></sub>
</p>

| PN532 pin | ESP32-S3 | Direction | Notes |
|---|---|---|---|
| `VCC` | **3V3** | — | **Not 5 V.** |
| `GND` | `GND` | — | Common ground. |
| `TXD` | **GPIO44** | PN532 → ESP32 RX | Crossed. |
| `RXD` | **GPIO43** | ESP32 TX → PN532 | Crossed. |
| `RSTO` | — | — | **Not connected.** The firmware defines no reset pin and never drives one; `config.h` declares the UART and nothing else. Leave it unwired. |
| `IRQ` | — | — | Not used. |

**Module DIP switches: both to `0` / OFF.** That selects HSU on the usual red V3
boards (`0 0` = HSU, `1 0` = I²C, `0 1` = SPI). Clones vary — read the table
silkscreened on your own module.

**Link settings:** UART1, 115200 baud, 8N1.

### The crossed-wires rule

`TXD` on the reader goes to the ESP32's **RX**, and `RXD` goes to the ESP32's
**TX**. Transmit talks to receive. If `getFirmwareVersion()` returns 0 at boot,
swap these two wires before you change anything else — it is the cause far more
often than not.

---

## ⚠️ Do not use GPIO6 and GPIO7

On this board GPIO6/7 are an **I²C bus** (camera header) and carry **pull-up
resistors**. The QMI8658 accelerometer is *not* there — a scan of this board
answers on the touch controller's bus, SDA 48 and SCL 47, at `0x6B`, and finds
nothing at all on GPIO6/7. The warning below is unchanged either way: the
pull-ups are what corrupt a UART, and an empty bus still has them.

Wiring the PN532's UART there produces a link that looks alive and is quietly
corrupt: random UIDs, `READ` commands that fail or return
garbage, tags that read once and never again.

GPIO6/7 appear in some early notes for this project and in the pin table of the
prototype's first-draft README. **That draft predates any hardware testing and is
wrong.** The bench-verified pins are 43 and 44.

### Why 43/44 are free

The ESP32-S3R8 on this board has fewer usable pins than the datasheet count
suggests:

| GPIO | Why it's unavailable |
|---|---|
| 0 | Strapping / BOOT button |
| 19, 20 | Native USB D−/D+ |
| 26–32 | SPI flash |
| 33–37 | Octal PSRAM |
| 45, 46 | Strapping |
| 47, 48 | Touch panel I²C (see below) |
| 6, 7 | On-board I²C with pull-ups — see above |

43 and 44 are the classic `U0TXD`/`U0RXD` pins. They are free here **because the
serial console runs over native USB-CDC**, not over UART0. This is why
`platformio.ini` must keep `-DARDUINO_USB_MODE=1` and
`-DARDUINO_USB_CDC_ON_BOOT=1` — dropping those reclaims 43/44 for the console
and breaks the reader.

---

## On-board peripherals (already wired, for reference)

You do not wire these — they are on the board. They are listed because they
explain which pins are unavailable.

### Display — SPI3

| Signal | GPIO |
|---|---|
| `SCLK` | 39 |
| `MOSI` | 38 |
| `MISO` | 40 |
| `DC` | 42 |
| `CS` | 45 |
| `BL` (backlight) | 1 |

Panel orientation is **rotation 2** — portrait, rotated 180°. Anything else and
the touch coordinates stop matching what is drawn.

### Touch — CST816S on I²C0

| Signal | GPIO |
|---|---|
| `SDA` | 48 |
| `SCL` | 47 |
| Address | `0x15` |

---

## What the reader can and cannot do

These are properties of the hardware, learned the hard way. Design around them
rather than trying to engineer them away.

**Range is 2–4 cm.** That is the PN532's honest range with the module's own
antenna. Keep the antenna away from ground planes and from the display's metal
back — proximity to either kills what little range there is. The enclosure
designs in [models/](../models/) exist partly to hold the antenna at a sane
distance.

**The module powers down between commands.** On these modules only the *first*
command after boot answers; every later one times out on the ACK. The symptom is
distinctive and misleading: the reader reports itself ready, and then reads zero
tags forever. The fix is to send a wake-up preamble before *every* command rather
than only at startup.

**Initialisation needs retries.** The first attempt fails almost every time. Retry
every 2 seconds until the firmware version comes back non-zero — and check it a
second time *after* `SAMConfig()`, because a module that answers once and then
goes quiet is exactly the failure above.

**Read pages `0x04`–`0x0B` only.** 32 bytes covers everything TigerSpool needs
(product id, material, brand, colour, temperatures). Reading them as two 16-byte
transactions instead of eight 4-byte ones is dramatically more reliable on a
marginal HSU link. Keep a 4-byte-per-page path as a fallback: when the link is
poor, smaller frames survive better than large ones.

**Read several times per tag presentation.** A single successful read is not
evidence of a good read. Validate what came back — a written TigerTag has very
few zero bytes in those pages, so a payload full of zeros means a truncated
response, not a blank tag.

**The stock Adafruit PN532 library's UART driver is not adequate here.** It
returned `FF 00 FF 00` on this hardware. The prototype uses the Seeed/elechouse
`PN532_HSU` driver with local patches; see
[docs/MIGRATION.md](MIGRATION.md#the-vendored-pn532-library) for what those
patches are and how they will be carried over.

---

## Bringing a new build up

Check in this order. Each step rules out the failure modes above.

1. **Power.** 3V3 on the PN532's VCC. Not 5 V.
2. **DIP switches.** Both at `0` / OFF.
3. **Wires.** PN532 `TXD` → GPIO44, `RXD` → GPIO43. Crossed.
4. **Idle bytes.** With the reader powered and nothing near it, the ESP32's RX
   line should be silent. Continuous garbage means TX/RX swapped, the DIPs in the
   wrong mode, a 5 V level, or the wrong UART.
5. **Firmware version.** Ask the PN532 for its firmware version. Non-zero once,
   then non-zero *again* after `SAMConfig()`. A single non-zero followed by
   timeouts is the power-down problem.
6. **A tag.** Present a TigerTag; the UID and 32 bytes of page data should come
   back. If the UID changes every read, you are on GPIO6/7.

<!-- TODO(images): wiring photo — docs/images/wiring-hsu.jpg -->

---

## Not yet verified

Listed here rather than left implied. These need bench work before they belong
in the sections above.

- **Enclosure antenna placement.** The 2–4 cm figure is measured with a bare
  module. Read distance through each printed shell in [models/](../models/) has
  not been characterised.
- **PN532 module variants.** Verified on the common red V3 breakout. Other
  form factors (e.g. the flat NFC antenna variants) are untested.
- **A shared reset line.** `RSTO` on GPIO4 helps init; whether it is sufficient
  to recover a wedged reader at runtime, without a power cycle, has not been
  tested.

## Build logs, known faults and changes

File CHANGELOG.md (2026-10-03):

# Changelog

All notable changes to this project are documented here.

Format: [Keep a Changelog](https://keepachangelog.com/en/1.1.0/).
Versioning: [Semantic Versioning](https://semver.org/spec/v2.0.0.html).

## [Unreleased]

### Fixed

- **The FlashForge Creator 5 case has a corrected frame**, in the bare parts
  and in the Bambu Studio project, and its Fusion source is published beside
  them.

### Added

- **A Flash Studio project for the Creator 5**, beside the Bambu Studio one:
  the case sliced for the printer it goes on.

## [1.70.0] - 2026-09-28

### Changed

- **Reading a spool is more than twice as fast** - about 250 ms instead of 585.
  The chip's signature is still read and checked on every scan, never cached,
  but the ECDSA check runs in the background: the spool is sent, and the
  screen drawn, while it works.
- **The send result shows whether the spool is certified**, as the reader
  screen does - for brands that sign their spools, at the moment the spool is
  used.
- **A spool whose signature does not verify reads "Not certified"**, in plain
  grey, instead of a red "does not match".

### Added

- **A bench build** (`tigerspool-bench`) for diagnostics that must never ship:
  they sit inside `#if TIGERSPOOL_BENCH`, the release build does not compile
  them, and a check fails if one is left outside.

### Fixed

- **The screen no longer freezes for 1.5 s every thirty seconds.** The device
  reported itself to the account from the main loop - a TLS request that
  stopped the screen drawing and answering, in the middle of a scan or a send.
  It runs in the background now.

## [1.69.1] - 2026-09-28

### Fixed

- **A firmware update no longer stalls when the selected printer is an
  Anycubic in cloud mode.** The selected printer kept its connection during the
  download, and a cloud Anycubic's session beside it stalled the download at
  442 KB and left the device without a network until it restarted. A download
  now closes every printer connection, the selected one too, and the cloud
  session listens only for the slot reports it uses.

## [1.69.0] - 2026-09-28

### Added

- **Settings > Turn off.** The board has no power switch, so "off" is deep
  sleep with the panel dark and Wi-Fi down, and no button wakes it. Unplugging
  the USB cable and plugging it back in turns it on again, and the screen says
  so - with a battery fitted too, declared in Settings or not: the device then
  checks the battery pin every 3 s and boots when the charger lifts it (28 mV
  measured, full cell). In Settings it sits under Restart.

## [1.68.0] - 2026-09-27

### Added

- **Anycubic printers in cloud mode**, read and written. Tiger Studio writes
  the account's token and Anycubic's shared client certificate on the cloud
  printer's document; the device opens one session to Anycubic's broker for
  every cloud Anycubic on the account, and signs in as a web client so Tiger
  Studio and the slicer stay connected beside it. Proven on a Kobra X:
  connect, read and six writes. The first cloud Anycubic costs 50 load slots,
  each further one 4 - that second figure is not measured yet (#19).
- **The first printable case: a desktop stand** that fits beside any printer,
  with the spool on the left of the screen or on the right. Bambu Studio and
  Creality Print projects, every part on its own, and the Fusion source. The
  printable cases now live in `Model3D/`: the universal stand in `0.Desktop/`,
  then one directory per brand and one per printer model inside it
  ([Model3D/README.md](Model3D/README.md)).
- **Cases that clip onto the printer's screen**: the Creality K2 and K2 Pro,
  the Bambu Lab A1 and A2L, the FlashForge Creator 5 and Creator 5 Pro, and
  every Anycubic Kobra 3 - each a frame, a cover and a reader holder, with
  slicer projects and the Fusion source where there is one.
- **The README shows the device and where to print it**: the desktop stand as
  the base model, the printer integrations beside it, a MakerWorld link for
  every published model, the screens you tap through, every compatible
  printer with what to switch on first, and the FlashForge × TigerTag firmware
  that keeps Cloud and LAN on together on a Creator 5.

### Fixed

- **An Anycubic's grid no longer drops to one slot after a spool is sent.** The
  printer answers a set with a report carrying only the slot that was set, and
  the grid was rebuilt from it. LAN and cloud alike.

## [1.67.0] - 2026-09-23

### Added

- **The account page manages the account.** Signed in, the page the QR opens
  used to be one status line that refreshed onto itself: nothing on it signed
  out, and nothing anywhere synced. It now shows who is signed in - picture,
  name and address - signs out (after asking, since that restarts the
  device), and opens a drawer with every printer on the account: the same
  on/off switch the device's own list has, the same memory check behind it,
  and a button that syncs and redraws the list in place.

### Fixed

- **Signing in with an email no longer resets the device.** The web page ran
  the account sync itself, inside the request, on the main loop: a TLS
  handshake nested that deep overflowed the loop's stack the moment the
  sign-in succeeded, and the device rebooted with nothing saved. The sign-in,
  the Google pairing and the "Sync machines now" button now hand the sync to
  the task that already runs it on a timer. The page answers at once, and the
  screen stays usable for the ten seconds the sync takes - it used to hold
  still for all of them. Reported, with the decoded backtrace, in #15.

## [1.66.0] - 2026-09-21

### Changed

- **The battery is declared, not detected.** A box does not know whether a cell
  is on its connector: there is no sense line, the rail with an empty connector
  reads anywhere from 4.05 to 4.27 V depending on the board, and the charger's
  ripple - which a healthy cell damps - is not damped by a tired one. Both of
  our boards proved it, in opposite directions: one reported a battery it did
  not have, the other denied the pack it was running on, at 3.3 V, while
  running on it. So Settings now has a Battery row on every device, with one
  switch: yes or no. The level, the runtime and what the device tells the
  account all follow that answer.
- **Nothing that blocks starts in the half second after a touch.** Dialling a
  printer and beating to the account both open a TLS session on the main loop,
  and that loop is also what reads the back chevron: a handshake started the
  moment a finger lands is a press that appears to do nothing. Navigation comes
  first.

### Fixed

- **The screen could stop answering after a control redrew its own view.** A
  finger stays on the glass for ten reads or so; a screen rebuilt while it is
  down destroys the object LVGL believes is being pressed, and LVGL only clears
  that pointer for the deleted object itself, never for its children. Every
  later touch was then treated as a continuation of a press that no longer
  existed. Any screen rebuild now cancels the press in flight.
- **The printer list repainted the whole screen thirty to fifty times a
  second, doing nothing.** Two updaters ran on every pass of the loop and wrote
  what was already there: `lv_label_set_text` invalidates a label whatever it
  is handed, and `lv_obj_add_flag` invalidates an object when HIDDEN is in the
  mask even if it was already hidden. Both now write only on a change. Measured
  with `/screen.ver`: 29-55 frames a second at rest before, 0 after.
- `printer_ids` was always published empty, so Studio could not tell which
  printers a TigerSpool stands in front of. They were written to a single NVS
  key that the flash refused - 361 bytes, and this frozen 20 KB partition has
  no contiguous run that long left - and read back only when a sync reported a
  change. They are kept in RAM now, refreshed by every sync.

## [1.65.0] - 2026-09-21

### Changed

- The device document moved to `users/{uid}/tigerspools/{mac}` - plural, like
  every other collection of things under an account. 1.64.0 wrote the singular
  for one release and never created a document anywhere, because the account's
  rules refused every write, so there is nothing under the old name.

## [1.64.0] - 2026-09-21

### Added

- **The device declares itself to the TigerTag account.** It writes
  `users/{uid}/tigerspool/{mac}` every 30 seconds - every 5 minutes with the
  screen off, and at once when a spool is written or a cable moves - so Tiger
  Studio can list it, show whether it is online, and see which printers it
  stands in front of. The identity, liveness and battery fields carry the same
  names a TigerScale writes. See `docs/PRESENCE.md`.
- The pairing page now says what it is adopting: `TigerSpool`, with the real
  firmware version. It announced itself as a "TigerTag Bridge" running `cfs_ui`.

  **The account's security rules must name this path before any of it is
  allowed** - every beat is refused until they do, and the device holds off for
  five minutes after three refusals rather than retrying for ever. The rule is
  in `docs/PRESENCE.md`. Several TigerSpools on one account are supported by
  construction: one document each, keyed by MAC.

## [1.63.0] - 2026-09-20

### Fixed

- **Signing in with an email and password no longer restarts the device.** One
  route rebooted and the other did not, which is what a user reported. The
  restart was hiding a real gap: the loop only reloaded the printer list when
  it had asked for the sync itself, so a sync done from the web page landed in
  NVS with nobody reading it back. It reads it back now, and nothing reboots -
  not after an email sign-in, not after a Google one, not after a manual sync.

### Changed

- The Cancel button stays for the whole of the scan screen, including the write
  that follows the read. 1.62.0 took it away the instant the chip was caught,
  which turned out to be a flicker a fraction of a second before the screen
  changed anyway.
- The screen that waits for a chip no longer prints the reader's error in red
  under its own instruction. "Hold it closer" in red, under "hold the spool
  against the box", while somebody is doing exactly that, reads as a fault they
  have caused. The error still goes to the serial log.
- The reader is called **Scan** on the home screen and in its own header, and
  its second line asks the question it answers: "What is this?".
- In reader mode, a tap anywhere on the spool's data goes back, not only the
  chevron: the hand that is not holding the spool should not have to find a
  corner.
- Reader mode marks a valid chip **Certified** rather than "genuine",
  translated in each language.

## [1.62.0] - 2026-09-20

### Changed

- **The spool goes to the printer as soon as it is read.** The confirm step
  with its Send / No buttons is gone: choosing the slot and presenting the
  spool were the decision, and being asked a third time only stood between the
  user and the machine. Nothing new appears for the write itself either - the
  screen that asked for the spool stays exactly as it is, minus the Cancel
  button, which has nothing left to call off once the chip is caught. The
  write is over before a screen of its own could be read, and one that flashes
  past reads as a fault rather than as progress.
- The three screens of one send now share a title: the slot's name, alone.
  "Slot B2" on one and "B2" on the next read as two different places.
- **The screen after a send was rewritten.** One success screen instead of two:
  it confirms what was sent to the printer - the spool's colour, material,
  brand and diameter - and then names the next step in a green block, with the
  slot on its own line. It no longer shows what the slot held before, nor the
  colour the printer settled on. It stays five seconds, counted down by a bar
  that drains, and a tap anywhere ends it sooner.

### Added

- Reader mode shows the **drying** instruction the chip carries - temperature
  and hours on one line. The disc above it lost 8 px to make room, which is
  what a 320 px screen costs.

## [1.61.0] - 2026-09-19

### Added

- A home screen that asks what you came for: **Printers** or **Reader**. The
  printer list is one tap in, with a chevron back; the account and Wi-Fi state
  live on the home screen, which is where the device starts.
- **Reader mode**: put a spool on the pad and read it - colour, material,
  brand, finish, diameter, the two temperature windows, what is left on the
  spool, and whether the chip proved itself genuine. It is the NFC tester's
  question without the NFC tester's thirty fields, which stay in Settings.
- A **Write** row on the home screen, greyed and marked as coming: writing a
  spool from the device itself is not built yet, and the row says so rather
  than appearing one day and moving everything under it.

### Changed

- The account and Wi-Fi icons are on the home screen only. The printer list
  carries a back chevron, its title and the gear instead: 240 px does not hold
  all six, and the title was running under the icons.
- Settings returns to the screen the gear was pressed on.
- The reader row wears the same amber as the reader screen: one subject, one
  colour.
- Internal: a guard now fails the build when the device and the setup portal
  disagree about how many bars a signal is worth. The scale is written in two
  languages, in two files, and nothing but a person holding a phone beside the
  device would have noticed them drifting apart.

### Fixed

- Two NFC icons on one screen shared a single pixel buffer, so the second one
  drawn overwrote the first and both wore the second's colour. Each canvas icon
  now owns its buffer and frees it with the object.
- `scripts/flash.sh` no longer claims no board is plugged in when the
  PlatformIO virtualenv has lost its `esptool` module. It falls back to the
  copy that ships with the platform, and says so plainly if neither is there.

## [1.60.0] - 2026-09-18

### Changed

- **The Wi-Fi icon is calibrated for this radio, and it stops twitching.** The
  scale moved 10 dB: full strength is now -70 dBm rather than -60, so a network
  that works is no longer drawn as one that is failing - the ESP32 reads low,
  and by an amount that differs between boards, so the old scale worried people
  for nothing. The exact dBm is still printed beside the word. And the wave no
  longer moves every second when the signal wanders across a boundary: the
  reading is averaged once a second, and an arc is gained or lost only after
  3 dB past the line. A change of more than 15 dB is shown at once, because
  that is somebody moving the device rather than noise.

## [1.59.0] - 2026-09-18

### Fixed

- **An update could fail to install on a device with several printers.** The
  download opened its connection before the device had freed the memory a
  secure connection needs, and whether it succeeded came down to how much
  happened to be free: on a bench with seven printers linked it failed outright
  with 11 KB of contiguous memory where it needed 20. It now waits for the room
  - the printers step aside in a few milliseconds - and connects with 42 KB.
- **The screen woke but stopped answering.** After the display had gone to
  sleep once, taps did nothing at all: the sleep check and the drawing were
  both reading the touch panel, on the same bus, from two places.
- **The loading spinner on the first printer import is the right size and
  centred**, and says what it is waiting for. Padding on an LVGL arc is taken
  off the arc itself, so a 40 px spinner with 24 px of padding had 16 px left
  to draw in.

### Changed

- **The screen no longer freezes while the device talks to a printer.** Drawing
  and the touch panel now run on their own task, so a connection to a printer
  that is switched off - which blocks for over a second - no longer stops the
  interface. Measured on a bench with six printers: the panel went blind for
  7.9 seconds out of every 80, in gaps of up to 1.3 seconds; it is now 1.2
  seconds out of 80, and the worst gap is a tenth of a second. Scrolling stays
  smooth while a printer is being dialled, and a tap during it is no longer
  lost - it is acted on when the device comes back, instead of never.

## [1.58.0] - 2026-09-18

### Fixed

- **A device stuck on a distant access point now moves to the near one.** On a
  network with several access points sharing a name, the device chose once - at
  the moment it connected - and stayed there however bad the signal became. On
  the bench it sat on an access point at -73 dBm while another on the same
  network was at -48. It now checks once a minute and moves when another is
  clearly better. Moving costs a reconnection: the printers drop and come back
  within four to fifteen seconds, which is why it only moves for a large
  difference.
- **A spool write is never interrupted by the device changing access point.**
  Moving costs a reconnection, and one landing between Send and the printer's
  answer would turn a write into a failure the user watches happen. The device
  now stays where it is while a write is in flight and while a spool is being
  scanned, reviewed or sent.
- **A wrong Wi-Fi password is reported at once** instead of after a 30-second
  wait, and the log says why a connection was lost rather than only that it
  was.

## [1.57.0] - 2026-09-18

### Fixed

- **A board with no battery no longer shows a battery.** The charge is measured
  on a pin that reads the battery rail, and on USB that rail is held up by the
  charger whether a cell is plugged in or not - on one board at 4.27 V, on
  another at 4.01, which is where a real cell sits. A level alone cannot tell
  them apart, and the board has no pin to ask. The device now listens to the
  charger's own ripple instead: a cell swallows it, an empty connector does
  not. Measured on two boards, 2-3 mV against 7-22, and the answer takes a
  second.

## [1.56.0] - 2026-09-17

### Fixed

- **A Bambu AMS HT is now seen.** A printer reports its HT units as 128 and
  up, and everything above id 3 was being dropped: an X1C with two AMS and an
  AMS HT showed the two AMS and the external spool, and the dryer not at all.
  Reported with a full MQTT dump, which is what made it findable.
- **A Bambu with more than one AMS updates its slots in the background too.**
  The report from such a printer is about 9 KB and the background buffer held
  8, so it was dropped without a word - the slots only ever refreshed while
  that printer was the one on screen.

## [1.55.0] - 2026-09-17

### Fixed

- **The account stopped syncing on a device with many printers, and only the
  orange account icon said so.** The sync needs 16 KB of contiguous memory for
  its task; with seven printers linked the largest free block was 16 372 bytes
  - twelve short - and the mechanism that frees memory only ran once a sync had
  started, which this one never could. The room is now asked for before the
  attempt, and the log says how much memory there was when one fails.

### Changed

- Internal: the last Portuguese left in the firmware - status strings and
  comments in the printer backends - is now English, and the guard that checks
  for it knows the words it had been walking past.
- **The screen keeps moving while the printers are talked to.** Measured on a
  bench with six printers: the panel was blind for 8.9 seconds out of every 75
  - a Bambu report costs about 70 ms to read and they were all read back to
  back before the screen was allowed to draw. Three changes bring that to 7.9
  seconds and halve the typical gap: a read buffer in front of the MQTT socket,
  a frame drawn between printers rather than after all of them, and a loop that
  sleeps only as long as the interface says it can.

## [1.54.0] - 2026-09-17

### Added

- **A battery entry in Settings, on the boards that have a battery.** A
  battery that fills to the level, the charge as a percentage, the state in
  words, the voltage it was all worked out from, and how long is left - to
  empty on the cell, to full on the charger, from the first second and
  corrected as the device watches its own rate. On a board with no cell the
  entry is not there at all.
- **The level reads the same with the cable in and out.** A charger holds the
  voltage above the cell's own, and the device measures how much - at the
  moment a cable moves, which is the only moment it can be measured - rather
  than assuming it. It remembers the figure across restarts.
- `/api/batt` returns the same numbers as JSON, for anyone watching a device
  from a desk while the cable moves.

## [1.53.0] - 2026-09-16

### Fixed

- **A wrong language picked at first start can be changed back.** The Wi-Fi
  setup screen that follows the language choice now has a back arrow to the
  language list; there was no way back before. The arrow answers from the
  moment the screen appears: for almost a second after it was drawn, the
  device was starting its setup network and every touch was ignored.
- **The account pairing screen fits on the screen.** The instruction ran edge
  to edge, the address broke in two and the countdown was cut off at the
  bottom. The screen now has the same header as the Wi-Fi one, the address on
  a line of its own, the code under it and the countdown under that.
- **The address under the QR is the one the QR points at.** It read
  `tigersystem.io/pair`, which was written into the translations and answers
  404; it is now taken from the pairing link itself, so the two can never
  disagree again, and it is drawn at the largest size that fits it on one
  line. The pairing code is taken off it, whether the link carries it as a
  parameter or as the last part of the address, so the line is the address
  and nothing else.
- **An empty printer list offers a button, not an instruction.** It used to
  say "All printers hidden. Settings > Printers" and leave the rest to the
  reader; the home screen now carries a Select printers button that opens the
  picker.
- **The printer lists no longer run off the screen.** On the first-boot
  printer choice the Confirm button was sliced along the bottom bezel and the
  gauge clipped at the top; on the Settings printer list the last row was cut.
  Both lists were measured without the space the screen puts between its own
  rows.
- **An expired pairing code returns to the sign-in choice by itself.** It used
  to stop on an error screen that had to be tapped; a code nobody got to in
  ten minutes is not a failure, and choosing Google again fetches a fresh one.
- **"Scan the QR code"**: a shorter instruction above the QR codes, in every
  language.
- **The language list shows its scrollbar**, like every other list - nine
  languages do not fit on one screen and nothing said there were more.
- **The screen stays smooth when no NFC reader is connected.** The device kept
  retrying the reader in a way that froze the interface for more than a second
  in every three - scrolling stuttered and a tap took a moment to land, which
  showed on first setup before the reader is wired.

## [1.52.0] - 2026-09-15

### Fixed

- **Writing the external spool on a Bambu Lab printer works on current
  firmware.** The device addressed the external spool the old way, which an
  X1C on firmware 01.12 accepts and silently ignores - the slot kept its old
  filament. It now uses the addressing current Bambu Studio sends.

### Changed

- **A Bambu Lab slot is sent the filament's own Bambu filament id and
  temperatures.** The filament id comes from TigerTag's product page for a
  TigerTag+ spool, otherwise from the material table built into the device -
  instead of a guess from the material's name, which is now only the fallback.
  The type is the material family (a filled material keeps its filler), and the
  nozzle temperatures follow the same order as on a Creality: product page,
  chip, material table, default.

## [1.51.2] - 2026-09-15

### Fixed

- **The language screen's title no longer runs into the rotate button.** At
  first start it read "Choose your language", which in French touched the
  button beside it; it is now the one word "Language", as when the screen is
  opened from Settings.

### Removed

- **The rotate button on the first-start language screen.** It looked like a
  refresh button, and the accelerometer already sets the orientation on first
  start; it can still be changed under Settings > Display.

## [1.51.1] - 2026-09-15

### Changed

- **The languages in the language picker are written in bold.**

## [1.51.0] - 2026-09-15

### Added

- **Chinese.** The TigerSpool now speaks simplified Chinese - 中文 is the last
  entry in the language list, on the device and on the Wi-Fi setup page. The
  panel draws it from a subset of Noto Sans SC holding only the characters the
  interface uses, as the TigerScale does. The NFC tester's field names stay in
  English, as in every language.

### Fixed

- **The home screen's title follows a language change.** It kept the language
  the device had started in until the next restart.

## [1.50.0] - 2026-09-14

### Changed

- **The Wi-Fi settings screen is clearer.** The network gets a card of its
  own with the Wi-Fi wave, its name in bold and the signal as a word in colour
  - Excellent, Good, Fair, Weak - beside the dBm. The address, MAC and the
  Wi-Fi channel sit in a second card, in bold.
- **Changing network can be backed out of.** The setup screen opened from
  Settings > Wi-Fi > Change network now has a header with a back arrow: it
  closes the setup access point, rejoins the saved network and returns to the
  Wi-Fi screen. A first start, with no network to go back to, is unchanged.
- **The setup access point's password has a padlock in front of it**, so it
  reads as the Wi-Fi password rather than a second line of the network name.

## [1.49.3] - 2026-09-14

### Changed

- **Slot names are bold and larger** on a printer's slot screen - Ext., 1A,
  A1 - so the slot is easy to find at a glance.
- **A brand too long for its slot is cut with one dot, not three**, on every
  printer: "Durami." instead of "Dura...", two more letters to recognise it by.

## [1.49.2] - 2026-09-14

### Fixed

- **A Creality slot keeps the nozzle temperatures it is sent.** The printer
  stores them only when they are written as decimal numbers - 215.0, not 215 -
  and the TigerSpool sent whole numbers, so every slot it wrote read back 0/0.
  Measured on an Ender-3 V4: the same frame with 215.0 is kept, with 215 it is
  dropped. The TigerTag RFID Connect app always wrote them with a decimal
  point, which is why its writes kept their temperatures.

## [1.49.1] - 2026-09-14

### Fixed

- **A filled material keeps its filler in a Creality slot's type.** An ABS-CF
  spool is sent as "ABS-CF", not "ABS": the type is the material family plus
  its filler when the material has one, from the TigerTag material table.
- **The material table built into the device is current**: PA11-GF is now
  known as a glass-filled material and PC-PTFE as a filled one.
- **The 1.49.0 notes said a Creality printer recognises the filament.** It
  does not always: the notes under 1.49.0 now say what the printer keeps.

## [1.49.0] - 2026-09-14

### Fixed

- **A Creality slot is sent the filament's real values.** It used to receive a
  material id of "0" and fixed default temperatures. It now receives
  Creality's material id, the nozzle temperatures and the pressure advance, in
  the same frame the TigerTag Connect app sends. For a TigerTag+ spool they
  come from TigerTag's product page when the device can reach it; otherwise,
  and for every TigerTag, from the chip and the material table built into the
  device, so this works offline too.

  What the printer keeps, measured on an Ender-3 V4 with a CFS: the type,
  brand, name, colour and pressure advance land in the slot. The material id
  is kept only when brand, type and name match the printer's own material
  library - "Generic PLA" does, a spool sent under its own brand does not.
  The temperatures in this release did NOT land: see 1.49.2.
- **A Creality slot's material type is the material family.** A "PLA High
  Speed" spool is sent as type "PLA", taken from the TigerTag material table,
  because that is what the printer's type field means.
- **A slot no longer flickers back to its old spool right after a write** on
  a Creality: the device waits a moment before reading the slot again.

### Changed

- **Slot names and brands on a printer's slot screen are white**, not grey, so
  they read at a glance.

## [1.48.1] - 2026-09-11

### Changed

- **A new device starts at full brightness**, instead of 80%. Lower it any
  time under Settings > Display. A device that already has a brightness saved
  keeps it.

## [1.48.0] - 2026-09-11

### Fixed

- **The device connects to the nearest Wi-Fi access point, not the first one
  it hears.** On a home network with several access points under one name, it
  could stay attached to a distant one for good - through reboots - and show a
  weak signal while a TigerScale beside it showed full bars. On the bench it
  went from -79 dBm to -46 dBm, and from one ping in five lost to none.

### Changed

- **The three icons at the top of the home screen line up.** Account, Wi-Fi
  and settings are now the same height, on the same line, evenly spaced. The
  Wi-Fi wave was a third smaller than the other two, and the gaps between them
  were uneven.
- **Tapping the account or the Wi-Fi icon opens Settings**, like the gear.
  Only the gear used to answer.
- **The Wi-Fi icon shows full signal from -60 dBm**, then two arcs from -70
  and one from -80, the thresholds phones use. Full used to need -40 or
  better, so an excellent connection showed two arcs of three. The setup
  page's network list uses the same thresholds.

## [1.47.1] - 2026-09-11

### Fixed

- **A printer that moves to a new address is followed.** When your TigerTag
  account gives a printer a new IP, the device now uses it. Before, the address
  the device already held always won, so a printer that had moved stayed
  unreachable on TigerSpool for good while Tiger Studio talked to it fine - an
  AD5X did exactly that.
- **Printers no longer swap addresses and access codes when the account
  changes.** Adding or removing a printer in Tiger Studio shifted the device's
  list by one, and every printer after that point took its neighbour's address
  and code - a Bambu Lab would then refuse the connection with an access-code
  error, and a switched-on printer could turn into a different one. Each
  printer is now recognised by its serial number, wherever it sits in the list,
  and keeps its own settings and its own switch.
- **Two entries in the account for the same printer become one.** An old entry
  left at a previous address beside the current one used to show up as two
  printers, the stale one first. The newer entry wins.
- **A printer whose settings change reconnects straight away**, instead of
  staying on the old connection until something else closed it.

### Changed

- A printer newly added to your account arrives on the device switched off, as
  on first start, so it does not take room you did not choose to give it.

## [1.47.0] - 2026-09-10

### Added

- **The device tells you how full it is before a printer stops connecting.**
  Settings > Printers, and the Choose printers step at first start, show a
  **Load** bar with a percentage. Some printers take far more of the device's
  memory than others - a Bambu Lab or an Anycubic about ten times an Elegoo,
  a FlashForge or a Creality - so the limit is not a number of printers but how
  much they load it. A printer that would not fit is refused when you switch it
  on: the switch does not move, the bar turns red and says **Not enough room**.
  Switching a printer off always works. How it is counted, and every
  measurement behind it, is in docs/CONNECTION-BUDGET.md.

### Changed

- **The documentation says what the firmware does today.** Elegoo and Anycubic
  were still listed as not implemented; both read slots on real printers. A
  Bambu Lab in cloud mode is now documented as read only, which it is. The
  firmware README no longer says nothing builds, and the web installer's page
  shows the manifest that is actually published.

## [1.46.0] - 2026-09-10

### Changed

- **More printers can be connected at once if you use Bambu Lab in cloud
  mode.** Every Bambu Lab printer on your account now shares a single secure
  connection instead of opening one each. That connection is the most
  memory-hungry thing the device does, so a second cloud printer now costs
  about a fifteenth of what it did, and there is room left for others. Each
  printer still shows its own spools and its own status; only the connection
  behind them is shared. Printers in LAN mode are unaffected.
- The device answers faster on the network: Wi-Fi power saving is off, which is
  the right choice for something that runs from a wall socket.

### Fixed

- **The device can no longer freeze indefinitely.** If its main program ever
  stops responding, it now restarts itself within thirty seconds and records
  why, instead of staying frozen until it is unplugged.

## [1.45.2] - 2026-09-10

### Fixed

- **The printer you are looking at connects more readily.** The device was
  reserving far more memory than a Bambu Lab printer on screen actually uses -
  its large receive buffer lives in a separate memory the device has plenty of,
  and was being counted against the scarce one. Connection limits now use costs
  measured on real hardware, printer by printer.

## [1.45.1] - 2026-09-10

### Changed

- **The update page is one page now.** Opening it shows your version and a
  turning ring while it checks - the check has always started on arrival, but
  nothing on screen said so. If something newer exists, the offer appears under
  your version instead of replacing it: the download icon, the version you are
  on and the one on offer, and Install at the bottom of the screen.
- The card is labelled "Version" rather than "Installed version".

## [1.45.0] - 2026-09-10

### Changed

- **Bambu Lab printers are no longer polled.** The device asked each one for
  its entire state every eight seconds - about 81 KB a minute for two printers,
  for spools that had not moved. The printer already announces a spool change
  by itself, in a message five times smaller, so the device now listens instead
  of asking. Your screen updates exactly as before; the Wi-Fi does a fraction
  of the work.
- The update page puts **Install at the bottom of the screen**, and scrollbars
  appear only when a page actually has more to show.

### Fixed

- **Printer connections stopped dropping and reconnecting.** A four-second
  read limit added to keep the interface responsive was also cutting off large
  replies, so the device hung up on printers that were answering perfectly -
  once every poll. Four minutes of observation now show none at all, where
  there were four reconnections in two and a half minutes before.

## [1.44.0] - 2026-09-10

### Fixed

- **The device reconnects to Wi-Fi on its own.** It asked for the network once
  at startup and never again - so if the association failed at boot, or the
  access point dropped the device later, it stayed there with a lit screen,
  every printer red and no way back short of unplugging it. It now asks again
  after fifteen seconds and keeps asking. This is the most important fix in the
  release.

### Changed

- **The NFC Tester is a proper bench instrument.** It reads in English whatever
  language the device is set to - it is used beside a reader log and a
  datasheet, and two people comparing the same spool have to see the same
  words. One field per row, in a fixed order, with a colour bar across the top
  and the raw chip pages behind a HEX Code button.
- **A spool's readings stay on screen when you take the spool away.** They used
  to clear the moment the chip left the reader, which is exactly when you want
  to read them.
- **The colour bar shows two or three colours for bicolour and tricolour
  spools**, decided by the spool's aspect rather than by the colour bytes -
  black is a real colour, and an unused slot is stored the same way.
- Colours are shown in hex, the main one with its alpha byte, and the page dump
  is set in a monospace face so it lines up in columns.
- **Titles, menu rows and printer names are heavier and larger**, and buttons
  are set in a size meant to be read at arm's length.
- The NFC Tester has an icon of its own instead of borrowing the Display row's
  sun, and the sun now matches the other icons' size.

## [1.43.1] - 2026-09-09

### Fixed

- **The device can check for updates and refresh its account again while
  several printers are connected.** With six connections open there was still
  memory free, but not in one continuous piece large enough for a secure
  connection - so the update screen showed "manifest HTTP -1" and the printer
  list stopped refreshing. The background connections now step aside for the
  second or two a secure request needs, and come straight back. The printer you
  are looking at keeps its connection throughout.

## [1.43.0] - 2026-09-09

### Added

- **A "Choose printers" step when you set the device up.** Right after your
  account is linked, the device lists every printer on it with none selected,
  and you turn on the ones this box should talk to. An account with a dozen
  printers should not have a new device dialling all of them on its first boot.
  The step belongs to setup and to a factory reset; signing in again does not
  wipe what you chose.
- **A blue dot while a printer is being connected to**, green once it is, red
  when it is not. Red for a machine the device is actively dialling is wrong,
  and it is wrong for exactly the seconds you are standing there watching.

### Fixed

- **A printer that lost its connection now comes back on its own.** Once a link
  ran out of attempts it never tried again until you tapped the printer - so a
  device left alone through a Wi-Fi blink or a printer reboot ended up with
  every dot red and no way back. It now starts over after a minute.
- **The interface no longer freezes when the network goes bad.** Opening a
  connection blocks, and the underlying defaults are very long - fifteen seconds
  for an MQTT socket, two minutes for a TLS handshake. With one connection per
  printer, all of them retried at once when Wi-Fi dropped and the screen stayed
  lit but stopped responding. One printer is dialled at a time now, and the
  waits are capped at a few seconds.
- **Connections are no longer closed to keep memory in reserve.** Each one is
  priced before it is opened, and the safety limit only acts on a shortage that
  actually lasts, instead of on the brief dip an account refresh causes.
- The cards behind rows are a black interior with a grey outline, which is what
  the panel actually shows well; scrollbars are visible, the same everywhere,
  and no longer touch the rows or the header.
- A long title no longer pushes the header's rule off the screen.

## [1.42.1] - 2026-09-08

### Changed

- **The update screen shows both versions**, the one installed and the one on
  offer: `1.42.0 > 1.42.1`, the version being left in grey and the new one in
  orange. The caption "Version available" is gone - it spent a line saying what
  the number under it plainly was, while what you are updating *from* was not
  on the screen at all.
- The update page no longer repeats the installed version in a row of its own
  while an update is waiting.

## [1.42.0] - 2026-09-08

### Changed

- **Every printer gets its own connection.** Until now there was one backend
  object per brand, shared by every printer of that brand: two Bambus, or two
  FlashForges, could not both be connected, and the second inherited the
  first's answers. Each printer now has its own object, its own socket and its
  own slots. Two Bambu Lab printers show their own spools side by side.
- **Connections are opened while there is memory for them.** A TLS session
  costs about 40 KB of internal RAM, so a device with nine printers switched on
  holds roughly six links at once. The printer on screen is always served
  first; the others are opened in list order, closed if free memory runs low,
  and retried after a wait that grows. A printer without a link reads as
  disconnected, because it is.
- **The cloud slot notice is one message.** "Working only with LAN Mode + Dev
  Mode" in orange, the QR code, and "Scan for tutorial" beneath it.

### Fixed

- **A printer that is switched off no longer shows as connected.** A link
  asked its backend whether it was connected before ever dialling, and with a
  shared backend the answer belonged to the other printer. A Creator 5 Pro that
  was not on the network at all showed a green dot and another machine's four
  spools. A link must now dial for itself before it can report a connection.
- **Reloading the printer list could delete most of it.** With several
  connections open there was not always enough contiguous memory for a TLS
  request, and a sync that reached one brand out of six wrote its result as if
  it were the whole account: thirteen printers became three. A brand that does
  not answer now keeps what the device already knew about it.
- **A printer switched to cloud mode is recognised.** When an account holds
  both an old LAN document and the newer cloud one for the same machine, the
  newer wins. An A1 in cloud mode was still being dialled on the LAN, with an
  access code the printer had since changed.
- **Two Bambu printers no longer disconnect each other.** They shared one MQTT
  client identifier, so the broker dropped whichever had connected first. The
  identifier now carries the printer's serial number.
- **The QR code on the cloud notice is centred**, with an even white margin on
  all four sides instead of running into the edge a scanner needs.

## [1.41.0] - 2026-09-08

### Added

- **A Bambu Lab printer in cloud mode shows its spools.** The device connects
  to Bambu's own regional broker with the session Tiger Studio put in your
  account - it never signs in to Bambu itself - and reads the same report the
  LAN path reads, so the existing parser handles it unchanged. An X1C reachable
  only through the cloud now lists `Ext.` and `B1`-`B4` on the panel.
- **Tapping one of those slots says why it cannot be written**, on a screen of
  its own, with a QR code to the page about switching the printer to LAN mode.
  The slot is tappable on purpose: a cell that ignores a finger teaches nothing.
- **A Cancel button on the connecting screen.** It stops the attempt as well as
  leaving it - connections are held open across screens now, so walking away
  would have left a printer that is not answering retrying unseen.
- **The printer lists have a visible scrollbar.** Both call
  `lv_obj_remove_style_all`, which takes the theme's scrollbar with it, so the
  mode was set on lists that drew nothing - and eleven printers gave no sign
  there were six more below the fifth.

### Fixed

- **The selected printer now gets its brand's connection.** One backend exists
  per brand, and the first visible printer of a brand held it - so selecting a
  second Bambu showed a screen that never connected while the log reported the
  other one's address. Whoever the user is looking at takes it.

## [1.40.0] - 2026-09-08

### Changed

- **Refreshing the printer list shows a screen, not a tinted icon.** The
  account read takes about fifteen seconds, and a coloured glyph in a corner is
  a still picture - which is what makes somebody press the button a second
  time. A turning ring and "Importing printers" instead, until the answer is
  in; then straight back to the list, rebuilt. It also stops the list being
  touched while it is about to change underneath.
- **The refresh button is gone from the main printer list.** It belongs where a
  missing printer is noticed and dealt with, which is Settings > Printers - and
  its absence gives the main screen its full-size title back.

## [1.39.0] - 2026-09-08

### Added

- **Bambu Lab printers in cloud mode appear on the device.** They used to be
  dropped at import, so a printer you own simply was not there and nothing said
  why. They are listed now, and opening one explains itself: **cloud printer,
  read only**, with a QR code to the page that explains switching it to LAN
  mode. Their slots are not tappable, because a cell that looks pressable and
  can never do anything is worse than one that plainly is not - Bambu's cloud
  broker accepts a report subscription and refuses the command that sets a
  tray.

  **What is not here yet:** the slots themselves. Reading them needs a session
  against Bambu's own broker, and everything that needs is now known - see
  WORKLOG.md. Nothing is dialled meanwhile: a cloud printer is never probed and
  never gets a link, so it costs nothing to list.

### Fixed

- **A FlashForge's first slot is no longer split onto its own row.** The
  station has four slots, 1A to 1D, and none of them is an external spool - so
  an AD5X showed 1A alone above the other three.

## [1.38.2] - 2026-09-08

### Added

- **The refresh button is on the main printer list too**, not only in Settings.
  Both ask the account now rather than waiting out the five-minute cycle, and
  both turn amber while the sync runs.

  Fitting it on the main screen costs its title a size: four controls and a
  word share 240 px, and the offsets there are measured off a capture rather
  than chosen - at the old size "Imprimantes" ended at x=114 and the refresh
  glyph began at 117.

## [1.38.1] - 2026-09-08

### Changed

- **The refresh button moved to Settings > Printers**, where it belongs: that
  is the screen where a missing printer is noticed. It has a header of its own
  with room for it, so the home screen goes back exactly as it was - full-size
  title, three controls.

## [1.38.0] - 2026-09-08

### Added

- **A refresh button in the printer list's header.** The list already reloads
  itself every five minutes, which is right for a box on a shelf and useless to
  somebody who has just added a printer in Tiger Studio and is standing in
  front of the device. The button asks the account now. It is the progress
  indicator too - it turns amber while the sync runs, because a control that
  does something invisible for fifteen seconds gets pressed again, and again.

### Changed

- **The printer list's title is a size smaller.** Four controls and a title
  share 240 px: at the old size "Imprimantes" ended at x=114 and the refresh
  glyph began at 117, which reads as one run of ink. Only this screen changes -
  every other has at most a chevron beside its title.

## [1.37.0] - 2026-09-08

### Added

- **Several printers stay connected at once.** Every printer you leave switched
  on in Settings gets its own live session, kept open whatever screen you are
  looking at - so opening one is instant instead of a connection you wait for.
  Four brands were held open together on the bench: Creality, Snapmaker, Elegoo
  and Anycubic.

  It costs almost nothing, which was measured before it was written: a plain
  MQTT session is about 3 KB of internal RAM and a TLS one about 38 KB, and
  three TLS sessions open together still leave 79 KB free.

  **The limit this leaves:** two printers of the SAME brand cannot both be
  connected, because a backend holds its state in file statics. Whichever is
  first in the list wins.

### Fixed

- **Snapmaker never connected at all, and said nothing about it.** Moonraker
  answered **403 Forbidden** to the WebSocket upgrade and the client fired no
  event, so a printer answering perfectly over HTTP looked exactly like one
  switched off. The cause is a default nobody would look for: the WebSocket
  library sends `Origin: file://` on every handshake, and Moonraker refuses an
  origin that is not in its `cors_domains`. The same upgrade without an Origin
  is accepted.
- **A Snapmaker showed no vendor.** `filament_vendor` was in every report and
  never read, so four spools Moonraker names R3D, Generic, Generic and
  Snapmaker all showed a dash. The variant joins the family too, the way the
  printer's own screen writes it: "PLA Silk", not "PLA".
- **Writing to a Snapmaker put the whole name in the wrong field.** It sent
  `FILAMENT_TYPE=PLA_High_Speed` where the printer keeps a family and a variant
  separately. Split at the first space now, so a written slot reads like the
  ones the printer wrote itself.
- **A Snapmaker's four extruders are on one row.** No external spool exists on
  a U1, so nothing should be split off onto a row of its own.
- **A black spool was an invisible cell.** The panel's ground is black and so
  are plenty of filaments; the colour was right and the slot looked empty. A
  hairline edge fixes it.
- **A long vendor name no longer wraps** and takes its row's height with it.
- **The dots on the home screen tell the truth.** They came from the
  reachability probe alone, which walks one printer at a time and expires - so
  a printer the box was actively talking to could show red between two sweeps.
  An open link lights the dot.

### Changed

- The WebSocket timeout goes from 1200 ms to 2500. 1200 was set to stop a
  five-second freeze per attempt on an unreachable printer; the probe gate does
  that job now, and the same macro is also the deadline for an upgrade
  response.

## [1.36.1] - 2026-09-08

### Fixed

- **An Elegoo with its Canvas hub connected no longer shows an empty `Ext.`.**
  On a Centauri Carbon 2 the hub and the single spool are the same feed path:
  plug the Canvas in and the external holder stops existing, unplug it and the
  four trays do. It is one or the other, never both, and drawing an empty
  external cell beside four full trays invented a fifth place a spool can be.
  Four trays with the hub, one external spool without it.

## [1.36.0] - 2026-09-08

### Fixed

- **Elegoo and Anycubic now connect. The credentials had been there all along.**
  The import kept two lists of field names forty lines apart - a server-side
  mask deciding what Firestore sent, and a client-side filter deciding what the
  parser kept - and nothing made them agree. Three fields were added to the
  first and not the second, so Firestore sent `mqttPassword`, `username` and
  `acuModelId` and the parser threw all three away before anything read them.
  On the bench that looked exactly like an account with no Elegoo access code
  and an Anycubic with no username. It is one list now, asked twice.
- **An Anycubic's slots are all on one row.** The grid drew the first slot
  alone above the rest, which is right for every brand that has a single
  external spool and wrong for Anycubic: its box -1 is a four-slot unit and
  none of them is external. A backend says which it is rather than the screen
  assuming.

### Verified on hardware

- **A Centauri Carbon 2 reads through the device**: `Ext.` empty, `S1` PLA
  Sunlu, `S2` PLA Silk Generic, `S3` PLA Sunlu, `S4` ASA Landu - the same four
  the printer reports to Tiger Studio.
- **A Kobra X reads through the device**, and its TLS handshake was the single
  biggest unknown in the protocol notes: mbedTLS completes it against the
  self-signed broker. `A1` PLA, `A2` PET, `A3` PLA, `A4` PC.

## [1.35.0] - 2026-09-08

### Changed

- **Every printer in the account reaches the device.** The limit was eight, and
  eight was worse than it sounds: the import walks the six brands in a fixed
  order and stops when full, so an account with more printers did not lose a
  random eight - it lost the LAST BRANDS, every time, which is Elegoo and
  Anycubic. The two newest backends supported printers that could never appear.
  Twenty-four now; a bench account of twelve imports whole, and NVS reports
  278 of 630 entries used.

### Fixed

- **The reachability probe knocked on the wrong port for the two new brands.**
  It has a port per brand and falls back to Creality's 9999, so Elegoo and
  Anycubic were probed on a port they do not open, marked unreachable, and then
  never dialled - a Centauri Carbon 2 reported "probe says unreachable" on the
  bench while Tiger Studio was talking to it. Every backend must be added to
  that table, and the failure when it is not is silent and total.
- **Anycubic kept dialling a broker it had no address for.** Its readiness
  guard tested the device id alone, so a record carrying that but missing the
  username connected to a server that had never been configured, printing
  "connecting..." for ever beside the line explaining why it could not.
- **A missing Anycubic credential now names itself.** All four come from the
  account and none can be read off the printer, so "one of them is missing" was
  not an answer anyone could act on.

## [1.34.0] - 2026-09-08

### Added

- **Elegoo, over the LAN.** MQTT on port 1883 with no TLS at all - the simplest
  transport of the six brands. Two protocols in one printer, and a cable
  decides which: with the Canvas hub plugged in, four trays are read with
  method 2005 and written with 2003; without it, the printer reports a single
  spool through 1061 and is written through 1055, and 2003 answers an error.
  The backend follows whichever is live. Slots are `Ext.` and `S1`-`S4`.
- **Anycubic, over the LAN.** MQTT on port 9883 with TLS against a self-signed
  certificate. The layout is read from the printer rather than assumed: box -1
  is the external unit and is **not** one spool - an ACE Pro 2 reports it with
  four slots - so it is drawn as a unit like any other, and a Kobra X with four
  ACE units reports twenty slots. Labels are `A1`-`A4`, `B1`-`B4`, one letter
  per unit.
- **The printer record carries named credentials.** Anycubic's broker needs a
  device id and a username beside the password, and its topics carry the
  printer's numeric model id. Three named fields rather than another overloaded
  pair: the sixth brand proved the pair does not generalise.

### Known limits

- **Neither backend has ever talked to a printer.** Both are written from
  protocol captures that Tiger Studio proved on real hardware, and both compile
  and are recognised by the account import - but a protocol read off a document
  and a protocol that answers are two different claims.
- **An account with more than eight printers drops the last brands first.** The
  import walks brands in a fixed order and stops at eight, and Elegoo and
  Anycubic are last in that order - so on a large account they are exactly the
  ones that do not arrive.
- **Anycubic in cloud mode is not supported and is not a variant of this.** A
  cloud-mode printer opens no local port at all; reaching it means Anycubic's
  own service, with signing secrets that live inside closed binaries. See
  docs/ROADMAP.md - it is blocked on a decision about what the account stores,
  not on firmware work.

## [1.33.2] - 2026-09-07

### Fixed

- **The boot screen had a line down each side.** The source artwork carried
  RGB(14,14,14) in its first and last pixel column, over 212 of the 320 rows -
  invisible in an image editor on a white desktop, and a bright line on a panel
  that inverts. 424 pixels, blacked out in the asset rather than papered over
  in the generator: the columns beside them are pure black, so nothing of the
  artwork was in them.

## [1.33.1] - 2026-09-07

### Changed

- **The two buttons on a confirm screen have room around them.** They ran edge
  to edge, which reads as a bar rather than as something you press, and they
  touched each other - "Restore" and "Cancel" a couple of pixels apart on a
  capacitive screen, one of which is not undoable. 78% of the width, and a gap
  between them.

## [1.33.0] - 2026-09-07

### Changed

- **Restart and Factory reset are a question and two buttons.** Restart said
  "Restart" in its header, asked "Restart the box?" underneath, and offered a
  button marked "Restart" - the screen saying one word three times, with a note
  about how long it takes and a promise that nothing is lost. Factory reset
  listed what it erased and then reassured you about what came back: two
  paragraphs arguing over how frightening the button should be. Each is now one
  question and two answers.
- **Factory reset is a red button, not a two-second hold.** The hold against a
  filling bar was safer on paper and much less obvious in the hand: the bar had
  to be learned, and a stray press followed by a stray hold is not that much
  rarer than a stray press. A button that says "Restore" in the destructive
  colour, beside one that says "Cancel", needs no teaching.

## [1.32.0] - 2026-09-07

### Added

- **French is written in French.** Every accent is back: Réglages, Écran, Mise
  à jour, Redémarrer le boîtier, Récupération des données, Lecteur prêt. They
  were left out because the font could not draw them - LVGL's built-in
  Montserrat carries ASCII, a degree sign and a bullet, and renders anything
  else as a blank box while logging nothing - so the translation was written
  around a limitation and looked like nobody had proof-read it.

  The faces are generated now, by `scripts/make-ui-font.sh`, from the same two
  source fonts LVGL uses and with LVGL's own symbol list, over
  `0x20-0x7F,0xA1-0x17F,0x2022`. That is Latin-1 and Latin Extended-A: enough
  for German, Spanish, Italian, Portuguese and Polish too, whose translations
  are still to be revisited by someone who reads them. `0xA0` is left out
  deliberately - a no-break space with no glyph is a visible one, which is how
  two brand names carrying one were found in the first place.

  The Display row's sun came along in the same pass, so the face that existed
  solely to carry it is gone and `scripts/make-icon-font.sh` with it.

### Changed

- **The font range is read from the repository rather than from the build
  tree.** It used to be extracted from LVGL's own sources under
  `firmware/.pio/libdeps`, which a fresh clone does not have - so the guard
  that validates every drawn string could not run until someone ran
  `pio pkg install`. The faces are ours and committed, so it needs nothing
  installed.

## [1.31.0] - 2026-09-07

### Fixed

- **The device rebooted while you used it, and which spool you scanned decided
  whether it did.** Every settings screen shared one signature variable, each
  folding its own constant into a hash of its contents - which is not a
  namespace: one screen's signature can land on another's. The NFC tester
  hashes the tag's product id, so scanning a particular spool and then walking
  back through Settings could make the Wi-Fi screen take its "nothing changed"
  path and write into a label LVGL had already destroyed. The assert named it
  exactly: `free() target pointer is outside heap areas`. Screens now claim
  their view by identity rather than by a number that can collide.
- **The NFC tester could not be left with a spool on the reader.** The back
  press was read twice - once to clear the tag, once to leave - and the second
  read found the flag already spent. The chevron cleared the tag and stayed
  put, and the spool put it straight back.
- **Reading a tag froze the interface.** `reader::read()` costs 575 ms - nine
  page transactions and a signature check - and the tester called it on every
  pass for as long as a spool lay there: one frame every 610 ms. It reads once
  per spool now, and the poll that watches for one is rate-limited. A read that
  never succeeds is also bounded in time; one that ran its full twenty attempts
  used to delay a back press by 6.8 seconds.
- **A switched-off printer made every screen stutter.** The WebSocket client
  opens its connection with a blocking connect, from the loop that draws the
  panel, so an unreachable printer cost 1.2 seconds a go - in Settings, in the
  tester, everywhere. The reachability probe already knew the answer; the link
  asks it before dialling now, and hangs up so the library stops retrying on
  its own.
- **The account sync ran on the same core as the interface.** Fifteen seconds
  of TLS and JSON at the same priority as the Arduino loop, every five minutes.
  It moved to the core that already carries Wi-Fi, along with the reference
  table update.
- **Watching the device made it stutter.** The whole 230 KB of a screenshot was
  serialised inside the web handler, blocking the main loop for as long as
  twelve seconds. The frame is copied once into PSRAM and streamed from there,
  with the panel free to run between chunks.
- **The QR code on the failure screen had a white bar across its last row of
  modules** - the row a scanner needs. It was a border growing outward from the
  code; the quiet zone is a white card sized from the code itself now.

### Added

- **The NFC tester is a data sheet.** Every field the chip carries, labelled:
  UID, product id, type, brand, aspects, kind and diameter, nozzle and bed
  windows, drying, timestamp as a date, quantity and what is left of it, the
  second and third colours, the HueForge distance, the custom message - and the
  raw pages underneath, because the question this screen answers is "did each
  value come off the chip correctly".
- **A spool can be proved genuine with no network at all.** ECDSA-P256 over
  SHA-256 of the UID and the two identity words, against the public key that
  ships with the protocol version. It is the one row on that screen that gets a
  colour, because it is the one row that is a verdict rather than a value.
- **The device downloads its own reference tables.** The tables compiled into
  the firmware are the floor - what a new box knows offline on its first
  second - not the source. It fetches the current ones into its filesystem and
  prefers those, per table, so a corrupt brand file cannot throw away a good
  material file, and a failed download costs nothing. Aspects, types,
  diameters, units and protocol versions joined materials and brands; all of
  them are refreshed by `firmware/tools/tigertag_db/db_update.py` at build time
  and by the device itself every six hours.

### Changed

- **"Lecteur NFC" is "NFC Tester"** - it is for testing what a read returns,
  and the name now says so.
- **Cancelling a scan no longer wears the colour of Factory reset.** Restart
  wears the colour it has in the menu instead of an installer's green.
- **A result you can read.** A success clears itself after four seconds; a
  failure waits to be acknowledged, and only the failure says so.

## [1.30.0] - 2026-09-06

### Changed

- **The connection failure screen says one thing.** It listed four causes under
  the QR code, and the most useful of them - a Bambu that has run out of
  connection slots - was below the fold on a 240 x 320 panel. A screen that has
  to be scrolled to reach its point has no point. Title, QR, "Scan the QR
  code", and nothing else; the causes live on the wiki, where they can be
  corrected without shipping firmware.
- **Wi-Fi strength is the TigerScale's own icon now, not colour.** The glyph
  used to go red, then orange, then green as the signal improved, so a
  perfectly usable -70 dBm looked like a fault - orange means "this needs your
  attention" everywhere else on this device. It is two stacked copies of
  LV_SYMBOL_WIFI now: a dimmed one showing the whole shape, and a lit one
  inside a container whose height is the signal. The arcs that light up are not
  objects, they are what a mask lets through of one glyph - which is why three
  arcs drawn by hand could never have matched. The dBm arithmetic came across
  with it, and the portal's network picker moved onto the same arithmetic, so
  one network is now described by one number in three places.

  The rule this settles: **colour carries a state, length carries a quantity.**
  Green connected, red no network - and nothing in between, so nobody has to
  wonder whether a yellow means "middling" or "look out".

### Added

- **Connecting to a printer now looks like something is happening, and says
  what.** A turning ring replaces the grid of empty cells that made an
  unreachable printer look like a broken box, and the line under it names the
  step: reading the account first - the address may be what was wrong - then
  "Attempt 1/3", "2/3", "3/3". A spinner says the device is busy; a counter
  says it has a plan and how much of it is left. Retrying spends three attempts
  rather than five: someone who has just pressed the button is standing there
  watching, and forty seconds of that is long enough to walk away from.

### Fixed

- **The scan, review and result screens no longer carry status dots.** Getting
  there is already the proof: the slot grid is only reachable through a printer
  that answered, and the tap that opened the screen came off that grid. Two
  green dots repeating it spent the top of the panel telling the user what they
  had just done.
- **A Creality status line came out empty after a send to the external
  holder.** That slot's name is deliberately null - it is a word, not a
  position, and comes from the translation table - and concatenating it made
  Arduino invalidate the whole string.
- **Tapping a slot did nothing.** The cell was a button, but the coloured block
  inside it covers almost all of it and a bare LVGL object is clickable by
  default - so every press aimed at a spool landed on the block and stopped
  there. The grid could only be operated by hitting the three millimetres of
  text above or below the colour, which reads as a screen that ignores you. The
  scan screen behind it was there the whole time.
- **The whole interface froze for five seconds at a time while connecting to a
  printer.** Measured on the bench: `backend->loop()` took 5006 ms per attempt,
  and the main loop ran once in that span. The WebSocket library opens its TCP
  connection with a blocking connect, from the same loop that draws the screen,
  and its default timeout is five seconds - which is what an unreachable
  printer costs, every attempt. Capped at 1200 ms, measured again at 1203 ms:
  a printer on the same network answers in tens of milliseconds, so this only
  shortens the wait for one that is never going to answer.
- **The spinner on the Wi-Fi connecting screen did not turn at all.** Two
  reasons at once, and either alone was enough. The screen rebuilt itself on
  every pass to update its countdown, destroying the spinner and creating a new
  one at zero; and the loop around it slept 250 ms between frames. Built once
  and written into now, and LVGL runs at full rate while the join is waited on.
  This is the first screen a cold boot shows.
- **The slot screen was building a new retry button every frame.** The
  unchanged path - the one taken on almost every loop - re-ran the header code
  meant for a rebuild, stacking a fresh button on the previous one for as long
  as the screen was up.

## [1.29.0] - 2026-09-06

### Added

- **A connection failure now explains itself.** After the five attempts, the
  screen says so and lists what to check — is the printer on, is it on this
  network, are its settings right in Tiger Studio Manager, and whether it is
  simply out of connection slots, which is routine on Bambu A1, A1 Mini, A2L,
  P1 and P1S. A QR code goes to `wiki.tigersystem.io` for the long version: a
  page can be corrected the day a new printer joins that list, and a string
  compiled into firmware cannot.

### Fixed

- **Switching printers could leave the previous one's filament on screen.** The
  session is held open now, and the link check saw the old printer still
  connected and declared itself up — so the header named one printer while the
  grid showed another's spools, and no reconnection was ever attempted. The
  link hangs up before it changes printer.

## [1.28.0] - 2026-09-06

### Changed

- **The printer connection is held open instead of being opened per screen.**
  It used to be opened by selecting a printer and closed the moment you pressed
  Back, so it existed in exactly one view and every return cost a reconnection.
  It now comes up as soon as there is a network and a chosen printer — before
  anyone navigates anywhere — and stays up.
- **It gives up after five attempts** and offers a retry instead of trying for
  ever. An indicator that spins indefinitely is one nobody believes, and a
  device that reconnects for ever to a printer that has been sold never stops
  using its radio. The retry re-reads the account first, because a changed IP
  is the most likely reason five attempts failed and retrying the same stale
  address five more times answers nothing.

## [1.27.0] - 2026-09-06

### Fixed

- **The interface no longer freezes while the network is busy.** Two blocking
  jobs were running inside the main loop, both on the home screen — the screen
  people spend their time on. Measured before and after rather than guessed:
  **600 to 1550 ms per pass, now 62 to 71 ms.**

  The reachability probe is a synchronous TCP connect with a 900 ms timeout,
  called every 1.2 seconds. One switched-off printer froze everything for most
  of every second.

  And the LAN sweep that finds a Creality whose address has changed probed four
  addresses per pass at 150 ms each — 600 ms a time, sixty times in a row,
  every time a Creality was unreachable.

  Both now run on their own task. What stayed in the loop is the half that
  rewrites the printer list, because the screens read that same array while it
  is being written. The sweep also went from four addresses per pass to
  sixteen: off the loop, the only cost is how long it takes.

### Changed

- **The slot grid puts the external spool on its own row**, with the CFS's four
  underneath on one line — they belong together and the external one is a
  different thing that happens to sit next to them. The rule generalises: first
  slot alone, the rest four to a line.
- The cards around each slot are gone, and the colour blocks are portrait
  rectangles. A block is already an object; wrapping it in a second rounded
  panel drew a box around a box.

## [1.26.0] - 2026-09-06

### Changed

- **The slot grid is laid out like the mobile app.** Slot name above, a
  coloured block with the material written inside it, the brand underneath —
  so somebody with both in front of them is reading one design rather than two.
  A block rather than a disc, because the material has to sit *inside* the
  colour and a word inside a circle either overflows it or shrinks it until the
  colour stops carrying. The text inside flips between black and white on the
  spool's perceived brightness, not on an arithmetic mean of its channels: the
  eye reads green as far brighter than blue, and a mean puts black on navy.
- Slots now carry the brand the printer reports, so the Creality vendor field
  reaches the screen instead of being written and never read back.

### Added

- **An NFC reader screen under Settings.** It reports the reader and then reads
  a tag: hold a spool against the box and it shows the colour, the material,
  the brand, the two temperature ranges and the product id. It answers "is my
  reader working" by working, rather than by claiming to — and it answers "what
  is actually on this spool", which nothing else did.

### Removed

- The reader dot from the slot screen. It was green on every screen, always,
  because the reader is always ready. A pixel that never varies reports
  nothing; what it used to claim is now provable on a screen that exercises it.
  Only the printer connection is still reported there, because that one varies.

## [1.25.0] - 2026-09-06

### Added

- **The home screen shows the account, next to the Wi-Fi.** The same person
  glyph the Account row in Settings uses, so the two are recognisably the same
  subject. Four states: red when no account is linked, blue while it is
  connecting, orange when the last exchange with the account failed, green when
  it succeeded.

  Green is a claim about the **last exchange**, not about holding a token. A
  device whose network dies stops claiming to be fine, instead of staying green
  until its token expires half an hour later — which is what the same indicator
  does on the TigerScale, and what its author recommended changing on both
  products. Blue exists so a healthy device does not announce "no account" for
  the few seconds of every boot before its token arrives.

### Changed

- `scripts/flash.sh` identifies the board by MAC before it writes anything, and
  refuses if the expected one is not plugged in. See the incident below.

## [1.24.0] - 2026-09-06

### Changed

- **Opening the printer picker refreshes the account.** It is the one screen
  where somebody is looking at the list and expecting it to match what they
  just did in Tiger Studio, so it is the one moment freshness is worth a
  request. The cached list draws immediately and the answer updates it when it
  arrives — nothing to wait for.

## [1.23.0] - 2026-09-05

### Added

- **The device works out which way up it is, on its first boot.** The board has
  an accelerometer; a device that has never been told its orientation now asks
  it once, before the language screen, so nobody has to read an upside-down
  question.
- **A rotate button on that first screen**, top right. The guess can be wrong —
  lying flat, gravity says nothing — and a device somebody cannot read is a
  device they cannot set up, so the correction is on the screen where the
  problem shows rather than three taps into Settings. Pressing it is a
  decision: automatic following goes off and stays off.
- **Orientation under Display is now Auto / 0° / 180°.** Auto is not a
  modifier on the choice, it is one of the choices, and one control removes the
  state where automatic is on, an angle is also selected, and neither explains
  the other. Auto follows the accelerometer while the device is running —
  checked once a second, and only on a reading the sensor is sure of.

### Fixed

- `docs/WIRING.md` said the accelerometer lives on GPIO6/7. It does not: a scan
  of this board answers at `0x6B` on the touch controller's bus, and finds
  nothing at all on GPIO6/7. The warning against putting the reader there is
  unchanged — the pull-ups are what corrupt a UART, and an empty bus still has
  them.

## [1.22.0] - 2026-09-05

### Fixed

- **A background sync no longer scrolls the Settings menu back to the top.**
  The menu never changes shape — eight rows, same order, always — so only the
  four values a sync can touch are written into it now: the printer count, the
  network, the account name and the waiting version, with their icon colours.
  Icons can be recoloured in place rather than rebuilt.

## [1.21.0] - 2026-09-05

### Changed

- **No screen is rebuilt to reflect a value any more.** Rebuilding throws away
  the scroll position, the focus and any animation in flight, and three screens
  were doing it many times a second:

  - the OTA progress ring restarted from zero on every percent reported,
    instead of sweeping once — which is the entire reason it is a ring;
  - the Wi-Fi screen rebuilt itself whenever the signal moved by a decibel,
    which on a real link is constantly;
  - the factory-reset bar rebuilt on every frame of the press-and-hold, so it
    could not animate at all.

  Each now builds once and writes the changing value into the widget that holds
  it. It is written into `AGENTS.md` as a settled rule rather than left as
  something to rediscover.

- **The live screen page reacts in a tenth of a second.** It polled the
  framebuffer on a timer — 150 KB an image, so the timer had to be slow, so
  moving between screens felt laggy. It now polls a four-byte paint counter
  every 120 ms and fetches the image only when the panel actually changed.

## [1.20.0] - 2026-09-05

### Fixed

- **Toggling a printer sent the list back to the top.** With more than a
  handful of printers, turning one on meant scrolling back down to reach the
  next — and the further down you were, the worse it got.

  The screen was rebuilt to show the new switch position, and a rebuilt list
  has lost where it was scrolled to. The switch is the only thing that changed,
  so it is now the only thing that changes: it flips in place, and the redraw
  signature no longer watches the visibility flags. What still rebuilds the
  screen is what only an account sync can change — which printers exist and
  what they are called.

## [1.19.0] - 2026-09-05

### Fixed

- **The Install button was cut in half by the bottom of the screen** when an
  update was available — the one control that page exists for. The line about
  Wi-Fi, account and printers being kept is gone, the spacing is tighter, and
  the page scrolls, so a longer translation cannot push a button off the panel
  again.

### Added

- `?preview=setupdate` renders the update page with a version waiting, and
  `?preview=updone` with none. Being behind is not a state a device can be put
  into on demand, and it is the state whose layout is tightest — which is how
  the cut button reached a release in the first place.

## [1.18.0] - 2026-09-05

### Fixed

- **The captive portal served the prototype's old configuration form.** A
  device that had joined Wi-Fi and later dropped to the setup access point
  showed the wrong page entirely. The route table was built twice — once when
  the device came up on the network, once when the access point started — and
  the ESP32 web server keeps handlers in a list where the first match wins, so
  the second registration of `/` was dead. It is registered once now and
  decides inside the handler, which cannot go stale.
- **The screen no longer sleeps during setup.** Every setup screen puts
  something on the panel that has to be read off it — a QR code to scan, a
  pairing code to type — and a screen that goes dark while someone is holding a
  phone up to it has failed at its one job. The sleep timeout applies to the
  home screen, where the device sits idle between spools.

### Removed

- **The prototype's configuration form is gone.** The portal replaced it for
  Wi-Fi, and printers come from the TigerTag account rather than being typed
  into a web form. On the local network `/` now goes to the account page.
- With it, `/save`, `/retry`, and `/reset` — the last of which wiped every
  stored namespace on a plain GET, with no confirmation and no authentication,
  from anywhere on the network. Factory reset is on the device, behind a hold.

## [1.17.0] - 2026-09-05

### Added

- **The Wi-Fi screen shows the signal in dBm.** The home screen colours its
  Wi-Fi glyph by strength, and "the icon is orange" is not something anyone can
  act on. A number is: it says whether to move the box or move the router.
  Green above −60, yellow to −75, orange below, red with no connection.

## [1.15.0] - 2026-09-05

### Fixed

- **The word "Text" in the header while the firmware downloads.** The download
  screen deliberately has no title, and an LVGL label created and then handed a
  null string keeps the placeholder it ships with. It appeared on the one
  screen that tells the user not to unplug the box — where anything unexplained
  is the most alarming. No title now means no label.
- **Google sign-in took minutes to complete after it had already been
  approved.** The device only learned of the approval when the phone's browser
  refreshed the waiting page — and the approval opens in a second tab by
  construction, which iOS then suspends. On a real phone the pairing sat
  unnoticed for two minutes, until the user thought to switch back to the first
  tab.

  Nothing about a pairing needs a browser. The device holds the token, so it
  now asks Google itself, every few seconds, for as long as the pairing screen
  is up. Approval completes whether or not anyone is looking at a phone.

## [1.14.0] - 2026-09-05

### Changed

- **The device checks for updates every six hours, not just once at boot.**
  This box sits on a shelf next to a printer and plenty of them will never be
  switched off — a device that checks once in its life learns about one update
  and then stops.

  It says so once per version, not once per check. A version already declined
  stays declined: repeating the notice every six hours is nagging, and nagging
  is what teaches people to dismiss without reading. A *newer* version speaks
  up again, because that is news. The Update row in Settings stays orange
  either way.

## [1.13.0] - 2026-09-05

### Changed

- The update notice is down to the badge, the version and two buttons. What an
  update keeps belongs on the update page, where someone is considering the
  question — not on a screen that interrupts them and has to be answerable at a
  glance.

## [1.12.0] - 2026-09-05

### Added

- **The device tells you when there is an update, instead of waiting to be
  asked.** It already checked once, twenty seconds after boot, and coloured the
  Update row orange — but that row is only seen by someone who went looking. A
  waiting update now says so on the home screen: the version, the line
  confirming Wi-Fi, account and printers are kept, and two buttons. *Install*
  starts it there and then; *Later* goes back and does not ask again this boot.
  It is held to the home screen, so it can never land on top of a spool being
  assigned.

### Fixed

- **Safari's "this form is not secure" warning on the Google button.** The
  button was a form, and Safari warns on any form posted over plain HTTP — even
  one carrying no data, which this one was. It is a link now. The same warning
  on the e-mail form is *correct* and stays: that password really does cross an
  unencrypted connection, which is the strongest argument for the Google route,
  where no password is typed at all.

## [1.11.0] - 2026-09-05

### Fixed

- **The network list is ready before you get there again.** It had been empty
  on first open since 1.7.0, filling in only after pressing "rescan".

  An ESP32 shares one radio between its access point and its station
  interface. Once a phone is associated to the access point, that radio is
  committed to serving it, and a scan started afterwards comes back with
  nothing — it does not fail, it succeeds and finds zero networks, which is why
  the earlier attempt at this looked for an error that was never reported.

  So the scan happens at the one moment it can: when the access point comes up,
  before anyone can join. It runs asynchronously, so the setup QR still appears
  instantly — that was the point of taking the *blocking* scan off this path in
  1.7.0, and removing the scan altogether was the mistake. The result is
  collected the moment it lands and served from there.

  The station interface also stays up now. Three places tore it down after
  every scan, and a scan cannot start on an interface that has not finished
  starting, so each one left the next scan worse off. Idle, it costs nothing.

  Verified on hardware: `scan cached: 18 network(s)` in the boot log before any
  client joined, and the endpoint serving eight named networks with signal
  strengths.

## [1.10.0] - 2026-09-05

### Fixed

- **The network picker came up empty on first open**, and only filled in after
  pressing "rescan". A regression from 1.7.0, where the blocking scan was taken
  off the access point's startup path to stop the setup QR appearing four
  seconds late. The replacement started the station interface and asked it to
  scan in the same breath — and a scan issued before that interface is up fails
  outright. The failure was silent, so the first attempt returned nothing.

  It now lets the interface settle, and retries once. The scan endpoint also
  stops reporting a failed scan as an empty list: those are different answers,
  and saying "no networks found" in a flat full of them left the user to guess
  that a button might help.

## [1.9.0] - 2026-09-05

### Fixed

- **The captive portal's DNS answered the wrong question, and that is why
  Android never opened the sign-in page.** The core's `DNSServer` writes an
  answer of type A whatever type was asked for, so a query for an AAAA record
  came back with a question section saying AAAA and an answer section holding
  four bytes of IPv4. That is not a valid response and a resolver may discard
  it. Android asks for A and AAAA in parallel and waits for both: the A answer
  arrived, the AAAA answer was thrown away, and the lookup sat there until it
  timed out — past the deadline of Android's captive-portal probe. The portal
  was up, encrypted and serving the page the whole time.

  iOS was never affected: its resolver is more forgiving and its probe retries.
  That asymmetry is what hid this behind two earlier theories.

  `net/captive_dns` replaces the core server. A queries get the device's
  address; every other type gets NOERROR with no answers, which is the correct
  way to say the name exists but has no record of that type, and lets the
  client use the address it already has. Verified against the running firmware
  with `dig`: `A` returns one answer, `AAAA` returns zero, both NOERROR.

### Added

- **A fallback QR, shown the moment a phone joins the setup network.** The
  screen switches from *join this Wi-Fi* to a QR pointing at the portal itself.
  If the sign-in sheet does not open on its own — on any phone, for any reason
  — scanning again lands on the page, with the address printed underneath for
  anyone who would rather type it. The page was always reachable; this is how
  someone reaches it without being read an IP address out loud.

## [1.8.0] - 2026-09-05

### Fixed

- **The setup access point is WPA2 instead of open, which is what stopped
  Android from opening the sign-in page.** A Galaxy S24 joined the setup
  network and never showed the captive-portal sheet. Open networks are why:
  Android treats one with no internet as a mistake to correct rather than a
  destination, and Samsung's adaptive Wi-Fi falls back to mobile data instead
  of probing for a portal. An encrypted network is handled as somewhere the
  user chose to be. iPhones were unaffected, which is what made this look like
  a timing problem for so long.

  **Nothing is typed.** The Wi-Fi QR format carries a key, so the phone joins
  in one tap exactly as before. The old reasoning for leaving it open — that a
  password would have to be read off a 2" screen — had a hole in it: the trade
  it described was never real.

  It also closes something that should not have been open. This portal accepts
  the user's home Wi-Fi password and their TigerTag password over plain HTTP,
  and on an open access point both crossed the air in clear to anyone in range.

  The key is derived from the MAC — `tiger` plus the last three bytes — so the
  QR, the screen and the radio always agree, and a factory reset comes back
  with the same key rather than stranding whoever wrote it down. It is printed
  under the network name for a camera that will not scan.

## [1.7.0] - 2026-09-05

### Changed

- **The sign-in page has been rebuilt.** It is the one screen of this product a
  stranger reaches by scanning a QR code, on a `192.168.x.x` address their
  browser decorates with a warning triangle, and it is where they are asked for
  a password — and it carried no mark of who was asking. It now opens with the
  TigerTag icon, keeps only what is needed to sign in, and ends with a way out:
  a Tiger Studio Manager button, GitHub, Discord and tigersystem.io.
  The password is masked with an eye to reveal it, the Google button carries
  the real Google mark and reads *Continue with Google*, the accents are back —
  that page is drawn by the phone's browser, so the panel font's ASCII limit
  never applied to it — and the firmware version is printed at the foot, read
  from the version macro rather than typed.
- **The Google pairing page was rebuilt with it, and the device joins in.** For
  as long as that page is waiting, the TigerSpool shows the same pairing QR and
  code on its own screen — so someone who started on their phone can finish on
  a computer by scanning the box instead of retyping a code, and a box that is
  waiting stops looking like a box that is idle. The page leads with *scan the
  QR code on the TigerSpool screen*, then the code, then *or* and a Continue
  with Google button for a browser already signed in. It no longer guesses
  where you are reading it: "open this link on a phone or PC" was advice to
  someone who had already done it, and equally wrong for someone who typed the
  address off the device's screen at a desk.
- Nothing on those pages is fetched from the internet. The phone reading it is
  joined to the device's own access point, where a remote font or logo fails
  silently — an empty box on the one screen where trust is being decided. The
  icon is served from flash by the device itself.

### Fixed

- **Choosing a language on a new device no longer freezes the screen.** After
  the language, the setup QR took several seconds to appear — long enough to
  read as a crash rather than as work. Two causes, both removed: the access
  point ran a full Wi-Fi scan on its way up, synchronously, blocking everything
  behind a list nobody had asked for yet; and the QR was drawn only after the
  radio had finished. The QR now goes up first — its SSID comes from the MAC
  and is known before the radio does anything — and the access point comes up
  behind it, in well under a second. The network list is fetched by the portal
  when it is opened, which is where it is actually needed.

## [1.6.0] - 2026-09-05

### Changed

- **The account icon is a person again, drawn the way the TigerScale draws it.**
  Two solid discs and no outline: the shoulders disc overflows the box and the
  clipped pixels are the whole mechanism — a circle cut off at the bottom reads
  as a bust. The previous attempt used outlines and came out as a different
  shape entirely.
- The printer and the sun follow the same silhouette rules the scale's own six
  icons follow: three strokes at most, one dominant form owning two thirds of
  the box, nothing thinner than 2 px, and recognisable when filled in solid.

- **The home screen shows Wi-Fi strength**, next to the gear, the way the
  TigerScale does. LVGL has one Wi-Fi glyph rather than a set of bar counts, so
  the strength is carried by colour — green above −60 dBm, yellow to −75,
  orange below, red when there is no connection. It is bucketed into those four
  levels before it reaches the redraw signature: raw dBm drifts by a few points
  every second on a still desk, and a screen that rebuilds on that loses the
  scroll position while someone is reading it.
- **Screen orientation is a setting.** Both mountings of the board exist, so
  which way up the panel is belongs to the user rather than to a build
  constant. Under Display, alongside brightness and sleep; applied immediately
  and remembered across reboots. LovyanGFX turns the touch coordinates with the
  display, so there is nothing to recalibrate.
- **The Settings rows are outlined rather than filled**, with chevrons at half
  the row height instead of a twelfth. On a black screen a filled row floats;
  an outlined one sits on the page, and eight of them read as a list rather
  than as eight separate objects. Matches the TigerScale.
- **The Account row shows the account's display name**, not its address — a
  name is what you call an account, an address is thirty characters that
  truncate to `benoit@atom…`. Its icon is green once signed in. Devices already
  in the field pick the name up on their next sync rather than waiting to be
  signed out and back in.
- **The live screen page is clickable.** `http://<device>.local/screen` already
  refreshed the panel image; a click on it is now forwarded as a touch, and a
  drag as a swipe. Navigating the device from a laptop no longer means
  hand-writing query strings.
- The printer icon keeps its original proportions. A heavier body and output
  tray followed the "one dominant form" rule and read worse on the panel.
- **The Display row now carries the real sun**, the same Font Awesome glyph the
  TigerScale draws, rather than an approximation of it. Drawing it was never
  going to work: LVGL primitives are axis-aligned rectangles, and that sun has
  eight pointed rays. `scripts/make-icon-font.sh` fetches Font Awesome 6.5.2 at
  a pinned tag and extracts the one codepoint — 4 KB of source, no change to
  the flash figure. The font file is cached locally and never committed.

### Fixed

- **The captive portal did not open on recent Android phones.** Scan the Wi-Fi
  QR code on a Galaxy S24, join the setup network, and the sign-in sheet never
  appeared — the portal was reachable the whole time, the phone had simply
  stopped looking. A background Wi-Fi scan was launched from the last line of
  the access point's startup, and a scan needs the station interface, which
  makes the radio hop channels. Android probes for a captive portal within
  about a second of associating, so that probe landed while the access point
  was away. It times out, the network is filed under "connected, no internet",
  and Android does not ask again. The scan now starts when the portal page has
  been served — which is itself proof the probe already succeeded — and the
  network list is still ready before anyone reaches the picker. iOS was
  unaffected because it retries its probe; Android's is effectively one-shot.

## [1.5.0] - 2026-09-05

### Changed

- **The update screen answers the question you came with.** Opening it now runs
  the check itself, instead of showing a "Check for update" button and waiting
  for you to state an intent you stated by arriving. The button remains for the
  two cases that still need it: no Wi-Fi, and retrying after a failure.
- **The progress ring replaces the progress bar.** While an image is being
  written the whole screen becomes a 152 px ring with the percentage inside it,
  no header and no way to leave — the download runs on its own task, and
  leaving would only hide it. Below it, a warning against pulling the plug: a
  half-written slot boots the old image, which is recoverable and looks like a
  brick for a minute.
- **The header is no longer a bar.** It is the same ground as the rest of the
  screen with a single rule under it, on every screen. The title reads as part
  of the page rather than a strip bolted above it.
- **The installed version is a row, and the state is a badge.** "Installed
  1.5.0" now uses the same row shape as the rest of settings, and the answer —
  up to date, an update waiting, or a failure — is a glyph in a coloured ring,
  legible before a word is read.
- The update channel row is gone. It offered one channel.
- **Orange is now a category of its own, not a weaker red.** Red means an action
  destroys something that cannot be rebuilt from the device; orange means it
  interrupts what is on screen and destroys nothing. Restart is orange, factory
  reset stays red. Without the distinction everything consequential turns red
  and red stops meaning anything.
- **A waiting update announces itself on the Settings menu**, in orange, with
  the new version on the row. The device checks once, twenty seconds after
  boot. That is the only announcement it gets: a spool reader is not a phone,
  and it is never checked on a timer afterwards.
- The update page now says "Version installed — v1.5.0", with the `v` the rest
  of the ecosystem prints, and answers the question people ask before pressing
  Install: Wi-Fi, account and printers are kept.
- **Every Settings row carries an icon, and the icon carries the state.** Green
  when something is reachable — Wi-Fi joined, account signed in, printers
  present — red when it is not, orange for what interrupts, red for what
  destroys. The label stays white, so eight rows read at a glance instead of
  turning into a colour chart. Taken from the TigerScale, which does the same.
- Icons LVGL has no glyph for are drawn rather than imported: a person for the
  account, a globe for the language, a printer, a sun. A kilobyte of code and
  no data — no font to generate and no licence to carry.

### Fixed

- The Settings menu showed an empty Wi-Fi network. `WiFi.SSID()` returns a
  String by value, and the temporary was dying before the menu read it. It
  never crashed; it just looked like a network problem.

### Changed

- Wording aligned with the TigerScale where the two devices name the same
  thing: "Your TigerSpool is up to date" as a sentence rather than "Up to
  date", and "Installed version" rather than "Installed".

### Fixed

- `scripts/flash.sh` failed with `PORT_ARG[@]: unbound variable` unless
  `--port` was passed. Expanding an empty array under `set -u` is an error in
  bash 3.2, which is what `/bin/bash` on macOS still is.

## [1.4.0] - 2026-09-04

### Fixed

- **The boot screen was gone before it could be read.** The device comes up
  faster than the eye, so LVGL began repainting over the logo within a fraction
  of a second — which looks exactly like an image that does not fit the screen.
  It is now held for one second, and the second is not wasted: the deadline is
  set where the image is drawn and only waited out at the end of startup, so
  LVGL, the language table, the storage read and the reader handshake all happen
  inside it. A board slower than a second to boot waits for nothing.

### Added

- `?preview=splash` draws the boot screen on demand, so it can be checked from a
  desk. It cannot otherwise be captured: it is shown before the web server
  exists, which is the whole point of drawing it that early.

## [1.3.0] - 2026-09-04

### Added

- **A boot screen.** Pushed to the panel from flash immediately after the display
  is initialised and before LVGL exists, so everything that follows — LVGL
  starting, the language table, the NVS read, the reader handshake — happens with
  the logo already up instead of behind a black screen. No timer holds it: it
  stays until the first real screen replaces it, so the device is never slower
  than it needs to be in order to look considered. 150 KB of flash, taking the
  app partition from 36.5% to 40.3%.

### Changed

- The installer's shopping list carries only what is actually bought. The jumper
  wires come in the PN532's box and the case comes off your own printer; both are
  in the bill of materials instead.

## [1.2.0] - 2026-09-04

### Fixed

- **The sign-in QR led to the Wi-Fi picker.** It carried the device's root URL,
  and that page opens with the network selector and puts the account form some
  forty lines below it — so a phone scanning it to sign in landed on a Wi-Fi list.
  The first control under the finger was also a save-and-restart for the network
  settings, on a device that had just joined a network. The QR now points at
  `/login`, a page with one job. Reported by a user.

### Added

- **A web installer**, at
  [tigertag-project.github.io/TigerSpool-RFID](https://tigertag-project.github.io/TigerSpool-RFID/) —
  plug a board in, press Install. Built on the same design system as the
  TigerScale installer, with the parts list, their links and the two things that
  otherwise cost an evening: Erase wipes the saved Wi-Fi and account, and a board
  offering no serial port is usually a charge-only cable.
- The installer speaks **nine languages**, one more than the device: Chinese
  renders in a browser and would reach the panel as empty boxes.
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

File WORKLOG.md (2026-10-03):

# Work log

Everything done since the last commit, in Keep a Changelog's headings, so a
release entry is synthesised from this file rather than re-derived from a diff.

**Append the moment a change is done**, not in a batch at the end. Written at the
end, this file is reconstructed from the diff — which is the exact thing it
exists to prevent.

**Describe the end state, not the journey.** An "Added X" and a later "Fixed X"
from the same cycle collapse into one entry. Anything reverted disappears
entirely: it never shipped.

At each checkpoint, synthesise this file into one line, use that as the commit
message, and reset it to this header.

---

## Unreleased

### Changed

- New wiring diagram (Cirkit Designer project 5b546f4e): board, PN532 and the
  optional 3.7 V battery on the BAT connector. `assets/wiring-diagram.jpg`
  replaced and the link updated in README.md and docs/WIRING.md; the README's
  alt text said "TX to SDA, RX to SCL", the reverse of the table - fixed.

### Fixed

- Creator 5 / 5 Pro case: a design error in the frame, corrected in Fusion
  (V5). `OriginalFiles/tigerspool-creator5-frame.3mf` replaced (6049 -> 8195
  vertices); cover and reader holder unchanged, byte for byte. The Bambu Studio
  project (`BambuStudio/tigerspool-creator5-full.3mf`) re-saved with the V5
  frame, supports placed again, and its two plate previews refreshed. A Flash
  Studio project for the Creator 5 itself added beside it
  (`FlashStudio/tigerspool-creator5-full.3mf`, 0.08 mm, 2 walls). The Fusion
  source is now in the repository, `Source/tigerspool-creator5.f3d`.

## 2026-09-28 - A faster, steadier screen, and the certified mark at send time (released in 1.70.0)

### Changed

- `reader::read(tag, background)`: the four signature pages are read on every
  read; with `background` the ECDSA verification runs on a core-0 task
  (`tagSig`) and the tag says `SIG_PENDING` until `reader::signatureOf()` has
  the verdict. No verdict is ever cached - a chip can be rewritten under the
  same UID. Measured: read 585 ms -> 247 ms. Send path and reader mode use it;
  the NFC tester stays in the foreground. Result screen shows the certified
  mark; `S_SIG_INVALID` is now "Not certified" in grey, no warning sign.

### Fixed

- Presence heartbeat off the main loop (`ttcloud::startAsyncHeartbeat`, task
  `ttBeat`, never overlapping an account sync): measured 1.5-1.6 s of frozen
  loop every 30 s, 10.5 s on the first beat after boot.

### Added

- Bench-only code has a switch: `TIGERSPOOL_BENCH` (`src/bench.h`, 0 by
  default, `BENCH_LOG()`), on only in the new `tigerspool-bench` environment.
  `scripts/check-bench-code.py` (in verify.sh) fails on a `BENCH:` / `TEMP:` /
  `DO NOT SHIP` marker outside `#if TIGERSPOOL_BENCH`, and on the switch turned
  on for `[env:tigerspool]`. Self-tested: a marker in a bench block passes, one
  outside or in its `#else` fails, the switch in the production env fails.

## 2026-09-28 - An update no longer stalls beside a cloud Anycubic (released in 1.69.1)

### Fixed

- OTA with a cloud Anycubic selected: `standDownForTls()` now drops the
  selected printer's link too while `ota::DOWNLOADING` (and triggers on
  entering the download, which follows an already-quiet check); the Anycubic
  cloud subscription narrowed from `.../<key>/#` to `.../<key>/multiColorBox/#`.
  Bench, same device and printer: before, stalled at 442260 of 2291936 bytes and
  the network wedged; after, slot written and verified, rebooted into 1.69.0,
  the cloud session back by itself.

## 2026-09-28 - Settings > Turn off, woken by the USB cable (released in 1.69.0)

### Added

- Settings > Turn off (`E_POWER_OFF`, `showPowerOff()`, `powerOff()` in
  main.cpp): Wi-Fi off, panel asleep, backlight pin held low through deep sleep
  (a floating pad would light it); setup() releases the hold. No button wakes
  it. Without a battery, USB out and back in is a power-on. With one, the cell
  keeps it powered, so it wakes every 3 s, reads the battery pin without
  lighting anything, and boots when the pin rises 6 mV above the lowest it read
  since going off (`stayOffUnlessPlugged()`). Measured with a full cell: 1411
  mV plugged, 1397-1401 unplugged, 1425 replugged. The check is armed whether
  or not a battery is DECLARED - a fitted, undeclared cell kept a first version
  off for good. Verified end to end on the bench, declared and undeclared: off,
  cable out, cable in, back up. Three strings in nine languages; the CJK subset regenerated
  for the new characters. Verified on the bench: off, silent on the network,
  back after a reset.

## 2026-09-27 - Anycubic cloud mode, printable cases and a README that shows them (released in 1.68.0)

### Added

- Printer-mounted cases: `2.Creality/K2-K2Pro/` (Creality Print projects for
  the K2 and the K2 Pro, a Bambu Studio one, three photos, Fusion source),
  `1.BambuLab/A1-A2/` (Bambu Studio project, Fusion source),
  `4.FlashForge/Creator5-5Pro/` (Bambu Studio project) and
  `6.Anycubic/Kobra3-Series/` (every Kobra 3 model: Bambu Studio project, Fusion source). Source paths and the
  Bambu account number stripped from every project.
- `Model3D/` replaces `models/`: `0.Desktop/` (universal), then numbered
  brand directories (`1.BambuLab/` ...), then printer model; inside a model,
  `Images/`, `Source/`, `OriginalFiles/` and one directory per slicer.
  Directories may use capitals, files are lower case, nothing has a space. `TEMPLATE.md` for model READMEs, a README per brand listing its
  models.
- The desktop stand (left and right versions: Bambu Studio and Creality Print
  projects, bare parts, Fusion source, previews taken from the projects). Before publishing, object names referring to
  politicians and every `source_file` path (`C:\Users\Admin\Desktop\...`)
  were removed from the 3MFs; the `.f3d` was unpacked and scanned, clean.
- README: new "The case" section (desktop stand as the base model, printer
  integrations for the K2, Creator 5, A1/A2L and Kobra 3), MakerWorld links
  for the four published pages, device screens in `assets/screens/` and the
  two stand renders side by side above the TigerSystem hero, LAN mode and the FlashForge × TigerSystem
  firmware under printer support. `Model3D/` README, the desktop, K2 and
  Creator 5 READMEs and the Creality and FlashForge brand tables carry the
  MakerWorld links; the Creator 5 README explains the firmware;
  PRINTER-COMPATIBILITY.md mentions it under LAN mode.
- Anycubic cloud mode: `anycubic_cloud.cpp` (one MQTT/TLS session to
  `mqtt-universe.anycubic.com:8883` per account, signed in as `web` beside Tiger
  Studio's `pcf`; getInfo/setInfo published on it as on the LAN) and
  `net/legacy_tls_client.cpp` (the broker's certificate is SHA-1 signed and it
  wants mutual TLS). Token, email and client certificate read from the cloud
  printer's account document, held in RAM only: NVS silently failed to store
  the 238-character token. Measured on a Kobra X: connect, read, six writes;
  51 KB for the session (budget 50 / 4). Tiger Studio's REST orders were tried
  and dropped - a second TLS session ran the device out of memory and wedged
  its network.
- Anycubic grid kept one slot after a set: a report smaller than the known
  grid now updates it in place instead of rebuilding it (LAN and cloud).
- README printer support: every model Tiger Studio Manager offers, plus the
  Kobra 3 Max V2 and the four Elegoo Centauri, one per row with LAN and Cloud
  columns (Cloud: Bambu Lab only, read only); every README table centred.
  Elegoo slots: `S1`-`S4` on a Combo (CANVAS), `Ext.` alone without it. The
  Bambu "A2" is gone - it does not exist; the case fits the A1 and the A2L.
- `scripts/clean-3mf.py` cuts source paths to file names and lists object
  names for review; `scripts/check-models.py` (in verify.sh) enforces the
  layout, plain lower-case names and no path in a 3MF, untracked files
  included.

## 2026-09-23 - the account page, and a sign-in that no longer resets the box (released in 1.67.0)

### Added

- `/login`, signed in, is the account page: picture (`photoUrl` from
  `accounts:lookup`, once per boot on the sync task, stored in NVS only when
  there is one), name, address, a sign-out button that asks first, and a
  drawer with every printer, an on/off switch each and "Sync machines now" at
  its top. Nothing navigates: `/api/account` is read back after a sync
  (`syncCount()` moves and `changePending()` clears) and after a switch.
  Switches move at once and are put back only on a budget refusal - the web
  server is on the loop, measured 5-6 s behind a printer handshake.

### Fixed

- Email sign-in reset the device (PR #15's backtrace: `handleTtLogin` ->
  `syncNow` -> mbedTLS on the 8 KB loop stack). All four web-side syncs now
  call `ttcloud::requestSync()`; the loop stack stays at 8 KB. Measured: the
  page answers in 0.3 s, the sync runs 11.7 s on its task, taps during it
  answer in 0.45-0.57 s.

### Documentation

- CODEMAP: the `gen_db.py` rows described a generator that no longer exists;
  the battery "threshold" row contradicted the declared battery. AGENTS: the
  ASCII-only and no-Chinese rows contradicted the fonts.

## 2026-09-21 - the battery is declared, and the screen always answers (released in 1.66.0)

### Changed

- Battery detection removed entirely; `battery::declare()` / `declared()`
  replace it, stored in NVS as `bdecl`, and `present()` is the declaration.
  Benoit: "le plus simple est que l'utilisateur declare sa batterie ... pas
  besoin de gerer ca par algorythme impreccis". The measurements that killed
  the heuristics, both on the same board: a flat pack at 3.31 V rippled 6.0 mV
  (read as "no cell"), and the same board with the pack REMOVED sat at 4.05 V
  rippling 1.7 mV (read as "a cell"). The other board, empty, sits at 4.27 V
  rippling 9 mV. No threshold separates those.
  The Settings row is now always present - it is the only way in to declare -
  and carries the percentage once declared. The switch sits at the TOP of the
  battery screen: at the foot it was below the fold, and every change of state
  rebuilds that view and resets the scroll, so the control moved out from under
  the finger reaching for it. The switch also moves in its own event callback,
  before main.cpp has decided anything: the loop can be a second deep in a TLS
  handshake when the finger lands, and a control that agrees a second later is
  one somebody presses twice. The printer list has done this since it was
  written, and the rest of the view follows in the same frame through
  `lv_async_call` - deferred, because rebuilding deletes the screen the
  callback itself belongs to and LVGL walks back into that object when the
  callback returns. Six toggles in a row, uptime 53 s -> 67 s: no reset.
  Verified on the board: declare on -> 71% and the
  measured view, declare off -> present=false, percent=-1.

### Fixed

- `screen_settings`: the printers view repainted at frame rate at rest. Found
  by measuring `/screen.ver` while Benoit reported the screen "moving on its
  own": 0 frames a second on the home screen, 29-55 on this one. `updateGauge`
  rewrote both gauge labels every pass, and `setReloadBusy` re-applied the
  HIDDEN flag every pass - LVGL invalidates on both regardless of whether
  anything changed. Both are now guarded by a cache, cleared where the objects
  are rebuilt (both the settings view and the first-boot chooser). 0 frames a
  second at rest afterwards, verified on the board with the battery.
- Battery presence: the ripple test is no longer asked below 4.15 V, where the
  level already answers. Found with a real pack at 3.31 V on the second bench
  board - ripple 6.0 mV, exactly RIPPLE_NONE_MV, so the device declared no cell
  while running on one. Benoit confirmed the pack was nearly empty. After the
  fix: "3.43 V is below the charger's own level - a cell is on the connector",
  8%.
- `printer_ids` published empty, always. Two faults, one on top of the other.
  The ids were written to NVS and read back only when a sync reported a change,
  so a sync that found the same printers left them in flash with nobody reading
  them - and then the write itself turned out to fail: `putString` returned 0
  for a 361-byte value with 130 free entries, because NVS wants a blob's
  entries contiguous inside one page and this frozen 20 KB partition (500/630
  used) has no run that long. They are kept in RAM now, refreshed by every
  sync; `PrinterCfg::docId` and the `pids` key are gone. A booted device
  publishes no ids until its first sync, which is a minute or two.
  Verified on the bench: `[presence] 2 printer(s) active, 2 id(s):
  4thj8F4g0SALP27GnrOm,t1nFx693oORWqjbd3ceD`.

## 2026-09-21 - the collection goes plural (released in 1.65.0)

### Changed

- Presence writes to `tigerspools/` (plural). The Firebase side pointed out
  that every account collection is plural - scales, printers, racks - and the
  singular would have been the one exception. Free to change: 1.64.0's writes
  were all refused, so no document exists under the old path.

## 2026-09-21 - the device declares itself (released in 1.64.0)

### Added

- Presence: `ttcloud::heartbeat()` and `ttcloud::deviceId()`, plus the
  scheduler in main.cpp (`presenceTick` / `presenceWatch`). One Firestore
  `documents:commit` with an updateMask, `last_heartbeat_at` as REQUEST_TIME,
  full-then-deltas, explicit nulls, display_name read before written.
  `docs/PRESENCE.md` holds the contract.
- `PrinterCfg::docId`: the printer's document id in the account, captured at
  import and kept in NVS as ONE newline-separated key (`pids`). Twenty-four
  separate keys would have cost about fifty of the hundred and thirty NVS
  entries this device has left, in a partition that cannot grow over the air.
- pairStart now sends kind `tigerspool`, model `TigerSpool`, the real version
  and the mDNS name.
- A change of IP address forces a beat. It is what somebody uses to reach the
  box, and the moment they need it is right after the router handed out a
  different one.

**Blocked on Firebase.** Every beat comes back `403 PERMISSION_DENIED` on the
bench: the account's security rules do not name this path yet. The rule needed
is in `docs/PRESENCE.md`. Until it lands, the code is verified only as far as
"builds, runs, sends a well-formed commit and backs off when refused" - which
it does: three refusals hold the next beat for five minutes, confirmed on the
bench board (4 attempts in 80 s, then the hold).

## 2026-09-20 - the sign-in reboot, and the scan flow settled (released in 1.63.0)

### Fixed

- Email/password sign-in rebooted the ESP32; Google pairing did not. Reported
  by a user. `handleTtLogin`, `handleTtSync` and the browser-driven Google poll
  all set `restartAt`, and the reason they needed to was in main.cpp: the
  ST_MAIN and ST_PRINTER sites tested `if (asyncTake(s)) { if
  (consumeChanged()) ... }`, so a synchronous `syncNow()` from the web handler
  - which hands nothing to asyncTake - never triggered `loadCfg()`. The two
  questions are now asked separately, and the three restarts are gone with
  `W_RESTART_SUFFIX`. `forget()` still restarts; dropping a session is the one
  case where starting clean is the point.
  Verified on the bench: a POST to /tt-sync runs the full account sync (12.7 s,
  16 LAN printers) with no `rst:` in the serial log and a frame counter that
  does not restart. The email path itself is UNVERIFIED here - signing in needs
  someone's real credentials, which I do not handle.

### Changed

- `S_SIG_VALID` is "Certified" and its translations - Certifié, Zertifiziert,
  Certificado, Certificato, Certyfikowany, 已认证 - replacing "genuine" /
  "authentique". The English word was used in all nine first; Benoit: "il faut
  le mettre dans la bonne langue". It is drawn in one place, the reader
  screen's header; the NFC tester shows "OK" and is untouched.
- `S_READ_MODE` is "Scan" (Escanear / Scansione / Skanuj / Digitalizar / 扫描)
  and `S_READ_HINT` is "What is this?" - the row now names the action and asks
  the question instead of describing the hardware. The home row's hint is
  clamped to ONE line: the first French wording wrapped and pushed the row's
  own label off centre.
- `screen_read::showTag` puts the back handler on the screen, the body and the
  header, and clears LV_OBJ_FLAG_CLICKABLE on the value rows and the colour
  disc - an LVGL container is clickable from birth and swallows the click.
- `showScan` lost its `errorOrNull` argument: a failed read is logged, not
  drawn. Benoit: "ne met pas le texte rouge quand tu attends la puce".
- The scan screen keeps its Cancel button for its whole life, including the
  write. Hiding it the instant the chip was caught was tried and thrown out:
  the write is short, so the button vanished a fraction of a second before the
  screen changed anyway, and a flicker on the way out makes the device feel
  unsteady.

## 2026-09-20 - the send, straight through (released in 1.62.0)

### Changed

- ST_REVIEW is now ST_SENDING, and it has NO screen of its own. The write
  starts by itself when the tag is read and the scan screen simply stays up,
  with one change: `showScan(..., caught=true)` drops the Cancel button, since
  from that instant there is nothing left to call off. Two earlier attempts
  were thrown away first - a full screen for the send (spool, temperatures,
  spinner), then the same screen with its words changed to "Sending" - because
  the send is short enough that anything shown for it flashes past. Benoit:
  "je veux pas voir l'ecran intermediaire car c'est trop rapide". `S_SENDING`
  went with them.
  The chevron still cancels while the product endpoint is being waited for;
  once `assign()` starts it is one blocking call and runs to its end.
  `S_SEND`, `S_NO` and `S_SLOT` are gone with the buttons and the old title;
  `S_SENDING` replaces them.
- The scan screen is titled with the slot's name alone, like the receipt.
- `screen_scan::showResult` rebuilt. Benoit: un seul ecran de succes, confirmer
  l'envoi et donner l'etape suivante -> in English: one success screen, confirm
  what was sent and name the next step. Layout: tick in a green ring, "Sent to
  the printer", the spool in a bordered card, then a fixed 68 px green block
  carrying S_INSERT_IN with the slot label ALWAYS on its second line - it must
  not change height between "1" and "AMS2-4", or the screen jumps between two
  spools. The colour-adaptation pair of swatches is gone with it.
- The success screen now runs a five-second countdown drawn as a draining bar,
  and the whole screen is clickable so a tap anywhere dismisses it. `msLeft` is
  deliberately OUT of the redraw signature: the bar's width is set on the early
  return, so the screen is not rebuilt sixty times a second.
- New strings S_SENT_TO_PRINTER and S_INSERT_IN, nine languages.
- Previews `scan`, `review`, `result`, `resultlong` (AMS2-4, the layout's worst
  case) and `resultfail`: these three screens had none, so nobody could look at
  them without a printer switched on and a spool in hand.

### Added

- The drying row on the reader screen (`S_DRYING`, nine languages): "55 °C -
  4 h" from `TagInfo::dryTemp` / `dryHours`. Benoit: "le séchage c'est
  important".

### Changed

- Reader screen geometry tightened to hold a fourth value row on 320 px: disc
  68 -> 60, row gap 6 -> 4, and 8 px off the two paddings above and below the
  brand line. Verified with a real spool: PLA High Speed, drying 55 °C - 4 h,
  matching the serial decode, with "Restant 476 g" fully on screen.

## 2026-09-19 - a home screen, and reader mode (released in 1.61.0)

### Added

- A home screen that asks what you came for: two 72 px rows, **Printers** with
  how many are online under it and **Reader** with what it does. The printer
  list is one tap in and comes back with a chevron.
- **Reader mode** (`ui/screen_read.cpp`): the spool's colour as a disc, the
  material, "brand - finish - diameter", the nozzle and bed windows, what is
  left on the spool, and a green "genuine" mark in the header. The NFC tester
  keeps every raw field and stays where it was, in Settings.
- A third home row, **Write**, greyed and not clickable: no chevron, no
  pressed state, "Coming soon" under it.
- Previews `main`, `read` and `readtag` for the three new screens.
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

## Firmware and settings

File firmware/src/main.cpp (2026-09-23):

// ============================================================================
//  TigerSpool RFID - main
//
//  Reads a TigerTag NFC chip and writes the filament into a printer slot.
//
//  State machine:
//    LANG -> WIFI -> (PROVISION) -> PRINTERS -> GRID -> SCAN -> REVIEW -> RESULT
//
//  Everything drawn lives in src/ui/ and is built from LVGL widgets. This file
//  owns the transitions and the data the screens read; it draws nothing itself.
//
//  Printers are imported from the user's TigerTag account into NVS namespace
//  "tigerspool" - they are never typed on this screen. See
//  docs/ARCHITECTURE.md and docs/ACCOUNT-DATA.md.
// ============================================================================
#include <Arduino.h>
#include <WiFi.h>
#include <WiFiClientSecure.h>
#include <esp_wifi.h>   // esp_wifi_set_bandwidth(), esp_wifi_set_country() - see staBegin()
#include <Preferences.h>
#include <nvs.h>
#include <LovyanGFX.hpp>
#include "LGFX_ESP32_S3_Touch_LCD_2.h"
#include "config.h"
#include "i18n.h"
#include "reader.h"
#include "battery.h"
#include "tt_db.h"
#include "printer.h"
#include "backend_creality.h"
#include "backend_ff.h"
#include "backend_bambu.h"
#include "backend_snapmaker.h"
#include "backend_elegoo.h"
#include "backend_anycubic.h"
#include "webcfg.h"
#include "net/ota.h"
#include "bambu_cloud.h"
#include "printer_budget.h"
#include "product_api.h"
#include <esp_task_wdt.h>
#include "imu.h"
#include "tigertag_cloud.h"
#include "ui/lvgl_port.h"
#include "ui/screen_home.h"
#include "ui/screen_setup.h"
#include "ui/screen_slots.h"
#include "ui/screen_scan.h"
#include "ui/screen_settings.h"
#include "ui/screen_read.h"
#include "version.h"

// ---- cores -------------------------------------------------------------
#define C_BG    0x0000
#define C_HDR   0x2104
#define C_TXT   0xFFFF
#define C_DIM   0x8410
#define C_SEL   0xFFE0
#define C_OKG   0x2606
#define C_ERR   0xF800
#define C_BTNR  0x9000
#define C_BTNG  0x0480
#define C_BTNB  0x1A4B

LGFX        lcd;
LGFX_Sprite canvas(&lcd);
bool        canvasReady = false;

Preferences nvs;
String  wifiSsid, wifiPass;
// Set from ARDUINO_EVENT_WIFI_STA_DISCONNECTED, reset to 0 (no reason codes
// use it) at the start of every staBegin() - see wifiReasonIsAuthFailure().
static volatile uint8_t wifiLastDisconnectReason = 0;
PrinterCfg printers[MAX_PRINTERS];
int     selectedPrinter = 0;
// Send was pressed on the review screen and is waiting, briefly, for the
// TigerTag+ product answer - see ST_SENDING.
static bool sendWaiting = false;

PrinterBackend* backend = nullptr;

// The printer link is held open, and held open is a state machine rather than
// a call. It used to be opened by selecting a printer and closed by leaving
// the slot screen: one view, no reconnection, and nothing anywhere else on the
// device could say whether the printer was reachable.
//
// Now: as soon as there is a network and a chosen printer, connect. Retry a
// bounded number of times, then STOP and say so - an indicator that spins for
// ever is one nobody believes, and a device that reconnects for ever to a
// printer that has been sold is one that never stops using the radio.
enum LinkState : uint8_t { LINK_IDLE, LINK_TRYING, LINK_UP, LINK_GAVE_UP };
LinkState linkState   = LINK_IDLE;
uint8_t   linkTries   = 0;
uint8_t   linkBudget  = 5;      // set from LINK_MAX_TRIES / LINK_RETRY_TRIES
uint32_t  linkStartAt = 0;
int       linkPrinter = -1;
// Five attempts, and long enough between them that a printer waking from
// standby gets a chance. A connect that has not landed in eight seconds is not
// about to.
static const uint8_t  LINK_MAX_TRIES = 5;
// A retry is asked for by someone standing in front of the box, watching a
// spinner. Five more attempts is forty seconds of that, which is long enough
// to walk away from. Three is twenty-four - long enough to be a real attempt,
// short enough to wait through.
static const uint8_t  LINK_RETRY_TRIES = 3;
static const uint32_t LINK_ATTEMPT_MS = 8000;
// How long a link that has run out of attempts waits before starting over.
static const uint32_t LINK_GIVEUP_RETRY_MS = 60000;
bool webStarted = false;
static void staNoSleep();          // defined beside LOOP_WDT_S
static void staBegin();            // likewise
static bool wifiReasonIsAuthFailure(uint8_t reason);   // likewise
static const char* wifiReasonStr(uint8_t reason);      // likewise

enum State { ST_LANG, ST_WIFI, ST_AP, ST_ACCOUNT, ST_MAIN, ST_READ, ST_SETTINGS, ST_PICK, ST_SET_WIFI, ST_SET_ACCOUNT, ST_SET_SCREEN,
             ST_SET_UPDATE, ST_SET_RESTART, ST_SET_FACTORY, ST_PRINTER, ST_GRID, ST_SCAN, ST_SENDING, ST_RESULT,
             ST_WEB_PAIR, ST_UPDATE_NOTICE, ST_SET_READER, ST_SET_BATTERY, ST_SYNCING, ST_CLOUD_SLOT, ST_CHOOSE_PRINTERS, ST_SET_READER_HEX };
State   state = ST_LANG;
// Which screen the gear was pressed on. Settings is reachable from both faces
// of the home screen, and coming out of it onto the other one moves the ground
// under somebody who only wanted to change the brightness.
State   settingsFrom = ST_MAIN;
// Whether the language screen was opened from Settings rather than reached on
// first boot. It decides two things: that the screen offers a way back, and
// where picking a language returns to. Inferring it from WiFi.isConnected()
// used to do both, and sent anyone whose network had dropped through first-boot
// setup again.
bool    langFromSettings = false;
bool    nfcReady = false;
uint32_t nfcLastTry = 0;
int     selSlot = -1;
TagInfo tag;
bool    sendOk = false;
String  resultMsg;
uint32_t stateSince = 0;

static int printerCount() {
    int n = 0;
    for (int i = 0; i < MAX_PRINTERS; i++) if (printers[i].type != PT_NONE) n++;
    return n;
}
static const char* typeTag(PrinterType t) {
    return t == PT_CREALITY ? "K2" : t == PT_FF_C5 ? "FF C5" : t == PT_BAMBU ? "Bambu"
         : t == PT_SNAPMAKER ? "Snap" : "--";
}

// ---- "is it online?" probe (TCP connect to the control port) ------------
// K2 = ws :9999 | FlashForge C5 = HTTP :8898 | Bambu = MQTT :8883
// Records when the last OK answer came in. A failed probe does NOT hide
// A single failed probe does not hide a printer: a TCP connect fails on a cold
// ARP cache or a congested link often enough that treating one miss as "gone"
// would make the list flicker.
static uint32_t pLastSeen[MAX_PRINTERS] = { 0 };
// The tag the NFC tester is showing, so the hex view can read the same one.
static const TagInfo* readerTag = nullptr;
static uint32_t pProbeAt = 0;
static int      pProbeIdx = 0;
static const uint32_t ONLINE_TTL_MS = 25000;   // stays "online" for 25 s without an answer

// The port the reachability probe knocks on, per brand.
//
// EVERY new backend must be added here, and the failure when it is not is
// silent and total: the probe knocks on the default - Creality's 9999 - gets
// nothing, marks the printer unreachable, and the link then refuses to dial a
// printer that is sitting there answering perfectly on its own port. Elegoo and
// Anycubic shipped in that state for exactly one release; a Centauri Carbon 2
// on the bench reported "probe says unreachable, not dialling" while Tiger
// Studio was talking to it.
static uint16_t ctrlPort(PrinterType t) {
    switch (t) {
        case PT_FF_C5:     return 8898;
        case PT_BAMBU:     return 8883;
        case PT_SNAPMAKER: return 7125;
        case PT_ELEGOO:    return 1883;
        case PT_ANYCUBIC:  return 9883;
        default:           return 9999;   // K2
    }
}
static bool probeOne(const PrinterCfg& p) {
    // A cloud printer has nothing on this network to knock on. Probing its
    // stale LAN address would mark it unreachable and hide it behind a failure
    // screen, when the truth is simply that it is somewhere else.
    if (p.type == PT_NONE || p.cloud || p.host.isEmpty()) return false;
    WiFiClient c;
    bool ok = c.connect(p.host.c_str(), ctrlPort(p.type), 900);
    c.stop();
    return ok;
}
static bool isOnline(int i) {
    return printers[i].type != PT_NONE && pLastSeen[i] != 0
        && (millis() - pLastSeen[i] < ONLINE_TTL_MS);
}
static int onlineCount();                   // fwd

// The reachability probe runs on its own task, and this is not a refinement -
// it is the difference between an interface that responds and one that does
// not.
//
// probeOne() is a synchronous TCP connect with a 900 ms timeout. Called from
// the main loop, as it was, a single switched-off printer froze everything for
// most of every second: measured at 600 to 1550 ms per pass on the home
// screen, which is the screen people spend their time on. Taps landed late,
// scrolling stuttered, and nothing on screen explained why.
//
// Nothing here needs to be in the loop. The probe produces one timestamp per
// printer and the loop only ever reads them; a 32-bit store is atomic on this
// core, so there is no lock to get wrong.
static TaskHandle_t pProbeTask = nullptr;
// Incremented once per printer probed. Until a printer has been LOOKED AT, the
// absence of a timestamp means nothing, and treating it as "offline" would stop
// the very first connection of every boot.
static volatile uint32_t pProbed[MAX_PRINTERS] = {0};
namespace disc { void sweep(); }   // defined below; the task drives it

static void probeTaskFn(void*) {
    for (;;) {
        // Slow right down when nothing answers at all - wrong network,
        // everything switched off. Otherwise the log fills with connect()
        // errors and hides anything useful.
        const uint32_t gap = (onlineCount() > 0) ? 1200 : 6000;

        if (WiFi.status() == WL_CONNECTED) {
            for (int k = 0; k < MAX_PRINTERS; k++) {
                int i = (pProbeIdx + k) % MAX_PRINTERS;
                if (printers[i].type == PT_NONE) continue;
                if (probeOne(printers[i])) pLastSeen[i] = millis() ? millis() : 1;
                pProbed[i]++;
                pProbeIdx = (i + 1) % MAX_PRINTERS;
                break;
            }
        }
        disc::sweep();   // the other blocking network job, off the loop for the
                         // same reason: 254 connects at 150 ms apiece.
        vTaskDelay(pdMS_TO_TICKS(gap));
    }
}

static void startProbeTask() {
    if (pProbeTask) return;
    // 4 KB: a socket, a connect, nothing else. Core 0, because the Arduino
    // loop and LVGL have core 1 and the whole point is to stay off it.
    xTaskCreatePinnedToCore(probeTaskFn, "probe", 4096, nullptr, 1, &pProbeTask, 0);
}

static int onlineCount() {
    int n = 0;
    for (int i = 0; i < MAX_PRINTERS; i++) if (isOnline(i)) n++;
    return n;
}
// Configured printers are ALWAYS listed. Reachability is an indicator, not a
// filter: the TCP probe is not reliable enough to hide anything, and a printer
// anything: a K2 or FlashForge with LAN Mode off answers RST on that port.
static bool printerVisible(int i) {
    return printers[i].type != PT_NONE && printers[i].visible;
}
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
void loop() {
    // Joined on the FIRST pass, not in setup(): setup() waits on Wi-Fi at
    // boot, which is slow on a weak link and entirely legitimate, and a
    // watchdog that fired there would turn a slow start into a boot loop.
    static bool watched = false;
    if (!watched) { esp_task_wdt_add(nullptr); watched = true; }
    esp_task_wdt_reset();                    // one feed per pass - see LOOP_WDT_S

    // The config page belongs to the network, not to a screen: as soon as there
    // is an address, http://tigerspool.local answers. That also means the setup
    // screens are reachable for a remote screenshot, which is how this UI gets
    // checked without someone standing in front of the device.
    if (!webStarted && WiFi.status() == WL_CONNECTED) onWifiUp();

    // Wi-Fi is dialled once at boot and never again - until now.
    //
    // If the association fails at startup, or the access point drops it later,
    // the device sits there for ever with a lit screen, every printer red and
    // no route to the account: watched happening twice today, once at boot and
    // once mid-session, on a link measured at -80 dBm where the radio is at the
    // edge of what it can hold. Arduino's own auto-reconnect did not bring it
    // back either time.
    //
    // So: after fifteen seconds down, ask again, and keep asking every thirty.
    // A device left alone on a bad afternoon has to end up connected, because
    // nobody is going to power-cycle it.
    if (!wifiSsid.isEmpty() && state != ST_AP && state != ST_WIFI) {
        static uint32_t downSince = 0, lastRetry = 0;
        if (WiFi.status() == WL_CONNECTED) { downSince = 0; lastRetry = 0; }
        else {
            const uint32_t now = millis();
            if (!downSince) downSince = now ? now : 1;
            else if (now - downSince > 15000 && now - lastRetry > 30000) {
                lastRetry = now;
                Serial.printf("[wifi] down for %lus - associating to '%s' again (%s)\n",
                              (unsigned long)((now - downSince) / 1000),
                              wifiSsid.c_str(), wifiReasonStr(wifiLastDisconnectReason));
                staBegin();
            }
        }
        roamCheck();
    }

    // The backlight is the only thing that sleeps. Everything below this line
    // keeps running whether the screen is lit or not.
    // Follow the accelerometer, but only when the user asked for it and only
    // on a reading the sensor is sure of. Checked once a second: turning a box
    // over is not a gesture that needs millisecond response, and polling an
    // I2C sensor the touch panel shares is not free.
    if (screenAutoRot) {
        static uint32_t lastLook = 0;
        if (millis() - lastLook > 1000) {
            lastLook = millis();
            int want = imu::suggestedRotation();
            if (want >= 0 && want != screenRotation) {
                screenRotation = want;
                lvgl_port::setRotation(want);
                nvs.begin("tigerspool", false);
                nvs.putInt("rot", want);
                nvs.end();
            }
        }
    }

    // The screen never sleeps during setup. Every one of these states puts
    // something on the panel that has to be READ off it - a QR code to scan, a
    // pairing code to type, a network being joined - and a screen that goes
    // dark while someone is holding a phone up to it is a screen that has
    // failed at its one job. The sleep timeout is for the home screen, where
    // the device sits idle between spools.
    const bool inSetup = (state == ST_LANG || state == ST_WIFI || state == ST_AP
                       || state == ST_ACCOUNT || state == ST_WEB_PAIR);
    lvgl_port::sleepTick(inSetup ? 0 : screenSleepSec, screenBrightness);

    // A heartbeat for the heap, every thirty seconds.
    //
    // Links open and close over hours, and each cycle builds and destroys a
    // backend. Whether that returns everything it took cannot be seen from a
    // single reading - only from the trend - and the device has already been
    // found at two kilobytes free with its network stack unable to open a
    // socket while it still believed it was on Wi-Fi. This line is what makes
    // the difference between a leak and a busy afternoon visible.
    {
        static uint32_t lastHeapLog = 0;
        if (millis() - lastHeapLog > 30000) {
            lastHeapLog = millis();
            int live = 0;
            for (int i = 0; i < MAX_LINKS; i++) if (links[i].state == LINK_UP) live++;
            // PSRAM alongside the internal heap, because the two answer
            // different questions. Internal RAM is what a socket, a TLS session
            // and an MQTT buffer come out of, and it is the one that runs out.
            // The 8 MB of PSRAM is almost untouched - LVGL's heap lives there
            // and nothing else does - so knowing how much of it is idle is how
            // anyone decides whether moving a buffer there is worth the work.
            Serial.printf("[heap] %u free, %u largest, psram %u/%u free, "
                          "%d link(s) up, wifi=%d rssi=%d\n",
                          (unsigned)ESP.getFreeHeap(), (unsigned)ESP.getMaxAllocHeap(),
                          (unsigned)ESP.getFreePsram(), (unsigned)ESP.getPsramSize(),
                          live, (int)WiFi.isConnected(), (int)WiFi.RSSI());
            // On the same half-minute, and on one line, so a board that has
            // been running for an hour can be read back rather than watched.
            Serial.printf("[batt] %d mV at the pin, %.2f V at the cell, %d%%%s\n",
                          battery::millivolts(), battery::volts(),
                          battery::percent(),
                          battery::present() ? "" : " (no battery)");
        }
    }

    // The account is kept fresh from here rather than from one screen, so the
    // freshness the header reports is a fact about the network and not about
    // where the user happens to be standing.
    if (!s_memtest && ttcloud::due() && !ttcloud::asyncBusy()) ttcloud::startAsyncSync();
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

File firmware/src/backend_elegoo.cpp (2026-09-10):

#include "backend_elegoo.h"
#include "i18n.h"
#include <WiFi.h>
#include <PubSubClient.h>
#include <ArduinoJson.h>

namespace {

// Internally: 0 is the mono extruder, 1..4 are the Canvas trays.
//
// What the UI SEES is one or the other, never both. On a Centauri Carbon 2 the
// hub and the single spool are the same feed path - plug the Canvas in and the
// external holder stops existing, unplug it and the four trays do. Showing an
// empty Ext. beside four full trays invents a fifth place a spool can be.
//
// So the exposed list is four trays when the hub is connected, and one external
// spool when it is not; mapUi() is the whole of the difference.
const char* const NAMES[ElegooBackend::ESLOTS] = { "", "S1", "S2", "S3", "S4" };

void applyTray(SlotState& s, JsonObjectConst t) {
    const char* type  = t["filament_type"] | "";
    const char* name  = t["filament_name"] | "";
    const char* brand = t["brand"] | "";
    const char* col   = t["filament_color"] | "";
    // `status` is 1 for an occupied slot, but a slot can carry a colour and a
    // type with status 0 on some firmwares - so the presence of a type is what
    // decides, and status only adds to it.
    s.known    = (t["status"] | 0) != 0 || strlen(type) > 0;
    // filament_name is the full "PLA Silk"; filament_type is the family. The
    // name is what a person reads off a spool, so it wins when it is there.
    s.type     = strlen(name) ? name : type;
    s.brand    = brand;
    s.selected = (t["status"] | 0) == 1;
    if (col && *col) {
        const char* h = (*col == '#') ? col + 1 : col;
        if (strlen(h) >= 6) {
            long v = strtol(h, nullptr, 16);
            s.r = (v >> 16) & 0xFF; s.g = (v >> 8) & 0xFF; s.b = v & 0xFF;
        }
    }
}

String hexColour(const TagInfo& t) {
    char buf[8];
    snprintf(buf, sizeof(buf), "#%02X%02X%02X", t.r, t.g, t.b);
    return String(buf);
}

// The fields the printer actually stores, in the shape both write methods take.
// filament_code 0x0000 is the captured "unknown" value: the slicer sends a code
// from a fifty-entry table keyed by type and name, and a tag carries neither of
// those keys - sending the wrong code would label the spool as a filament it is
// not, where 0x0000 simply says nothing.
String writeParams(int canvasId, int trayId, const TagInfo& t) {
    JsonDocument d;
    d["canvas_id"] = canvasId;
    d["tray_id"] = trayId;
    d["brand"] = t.brand;
    d["filament_type"] = t.material;
    d["filament_name"] = t.material;
    d["filament_code"] = "0x0000";
    d["filament_color"] = hexColour(t);
    d["filament_min_temp"] = t.nozMin ? t.nozMin : 190;
    d["filament_max_temp"] = t.nozMax ? t.nozMax : 230;
    String out; serializeJson(d, out);
    return out;
}

}  // namespace

void ElegooBackend::publish(int method, const String& params) {
if (!mqtt_.connected()) return;
String out = String("{\"id\":") + (++msgId_) + ",\"method\":" + method +
             ",\"params\":" + params + "}";
Serial.printf("[elegoo] -> %d %s\n", method, params.c_str());
mqtt_.publish(topRequest_.c_str(), out.c_str());
}

void ElegooBackend::onResult(JsonObjectConst res, int method) {
if (method == 2005) {
    JsonObjectConst ci = res["canvas_info"];
    JsonArrayConst list = ci["canvas_list"];
    if (list.isNull() || list.size() == 0) { canvas_ = false; return; }
    JsonObjectConst c0 = list[0];
    // `connected` absent means an older firmware that only reports the hub
    // when it is there; a present-and-zero means it is unplugged, and the
    // four trays it still sends are all empty strings. Believing them would
    // wipe four slots on screen every poll.
    canvas_ = !c0["connected"].is<int>() || (c0["connected"] | 0) != 0;
    if (!canvas_) return;
    for (JsonObjectConst t : c0["tray_list"].as<JsonArrayConst>()) {
        int id = t["tray_id"] | -1;
        if (id < 0 || id > 3) continue;
        applyTray(slots_[1 + id], t);
    }
    status_ = "Elegoo: canvas";
    return;
}
if (method == 1061) {
    JsonObjectConst m = res["mono_filament_info"];
    if (!m.isNull()) {
        applyTray(slots_[0], m);
        status_ = "Elegoo: mono";
    }
    return;
}
}

void ElegooBackend::onMqtt(uint8_t* payload, unsigned int len) {
JsonDocument doc;
if (deserializeJson(doc, payload, len)) return;

// The register acknowledgement names its error field "error" and puts "ok"
// in it on success, which is worth knowing before reading it as a failure.
if (doc["error"].is<const char*>() && strcmp(doc["error"] | "", "ok") == 0) {
    Serial.println("[elegoo] registered");
    return;
}
int method = doc["method"] | 0;
JsonObjectConst res = doc["result"];
if (!res.isNull()) {
    int err = res["error_code"] | 0;
    if (err) Serial.printf("[elegoo] method %d error_code %d\n", method, err);
    onResult(res, method);
}
}

void ElegooBackend::begin(const PrinterCfg& cfg) {
    host_ = cfg.host;
    sn_   = cfg.sn;
    // "123456" is the factory access code and the one every printer nobody has
    // touched still has. An empty field in the account means "not changed",
    // not "no password".
    pass_ = cfg.cc.length() ? cfg.cc : String("123456");

    for (int i = 0; i < ESLOTS; i++) slots_[i] = SlotState{};
    connected_ = false;
    canvas_ = false;
    status_ = "Elegoo: connecting...";

    // A fresh client id per connection. The printer keys its unicast response
    // topic on it, so two boxes on one printer must not share one.
    cid_ = String("TTG_") + String(random(1000, 10000));
    rid_ = cid_ + "_req";
    topRequest_  = String("elegoo/") + sn_ + "/" + cid_ + "/api_request";
    topResponse_ = String("elegoo/") + sn_ + "/" + cid_ + "/api_response";
    topStatus_   = String("elegoo/") + sn_ + "/api_status";
    topRegister_ = String("elegoo/") + sn_ + "/api_register";
    topRegResp_  = String("elegoo/") + sn_ + "/" + rid_ + "/register_response";

    mqtt_.setServer(host_.c_str(), 1883);
    // A full 1002 snapshot with a file list runs to a few kilobytes. Nothing
    // here approaches Bambu's 50 KB pushall.
    mqtt_.setBufferSize(8192);
    mqtt_.setKeepAlive(60);
    // A bounded wait, because this runs in the main loop.
    //
    // PubSubClient's socket timeout is FIFTEEN SECONDS by default, and a TLS
    // handshake in the Arduino client waits two minutes. With one printer per
    // backend that is now six of these in a row: when the network goes away -
    // and at -78 dBm it does - the loop stopped for long enough that the panel
    // was lit and completely unresponsive, which is what a frozen device looks
    // like to the person holding it. Nothing here is worth more than a few
    // seconds; a failed attempt is retried anyway.
    mqtt_.setSocketTimeout(4);
    mqtt_.setCallback([this](char*, uint8_t* p, unsigned int l) { onMqtt(p, l); });
    lastTry_ = 0;
}
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

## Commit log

2026-09-05 Never rebuild a screen to reflect a value
    The printer toggle was not the only place doing this. An audit of every redraw
    signature found three more, all rebuilding many times a second:
    The OTA ring hashed the download percentage, so it was torn down and rebuilt on
    every report - an arc that restarts from nothing a hundred times instead of
    sweeping once, which is the entire reason it is an arc. The Wi-Fi screen hashed
    the signal strength, which on a real link moves by a decibel or two every
    second. The factory-reset bar hashed the hold progress, so it rebuilt on every
    frame of the press and could not animate at all.
    Each builds once now and writes the changing value into the widget that hol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
    [lvgl_port.cpp]
2026-09-05 A sync no longer scrolls the Settings menu out from under you
    Named as still-broken in the last release, so here it is. The menu never
    changes shape - eight rows, the same order, always - and the only things a
    background sync can touch are four values and their icon colours: the printer
    count, the network, the account name and the waiting version. Those are written
    into the screen now instead of rebuilding it.
    icons::tint() recolours an icon where it stands, whether it is a symbol glyph
    or a handful of drawn strokes, so a row changing state does not take the list
    that holds it with it.
    The update path checks frame::screen() before it writes anything. Those
    pointers belong to one screen; bu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
2026-09-05 The board works out which way up it is
    A device that has never been told its orientation asks the accelerometer once,
    on its first boot, before the language screen - so nobody has to read an
    upside-down question to answer it.
    Two facts were measured rather than assumed, and both were worth measuring.
    The chip is at 0x6B on the touch controller's I2C bus, SDA 48 and SCL 47. An
    I2C scan of this board finds 0x15, 0x6B and 0x7E there and nothing at all on
    GPIO6/7, where docs/WIRING.md said the accelerometer lived. That line is
    corrected; the warning against putting the reader on GPIO6/7 is not, because
    the pull-ups are what corrupt a UART and an empty bus still has them.
    And the axis is X, no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
    [imu.cpp, main.cpp, screen_setup.cpp]
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2026-09-06 Never write firmware to a board without checking which board it is
    TigerSpool firmware was flashed onto the bench TigerScale four times. Both were
    plugged into the same Mac, the TigerSpool's port name disappeared, another port
    was present, and it was assumed to be the same device re-enumerated. It was
    not. Reading the MACs afterwards settles it: dc:b4:d9:24:99:18 is the
    TigerSpool, 20:6e:f1:9a:17:b4 is the TigerScale.
    It cost more than the TigerScale's firmware. Every build in that window went to
    the wrong board, so the TigerSpool kept running older code - and an hour was
    spent chasing an account icon that "rendered as a dot". It rendered correctly
    the whole time. What was on screen was the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
    [main.cpp, tigertag_cloud.cpp]
2026-09-06 Show a slot the way the app shows it, and give the reader its own screen
    The slot grid now uses the mobile app's cell: the slot name above, a coloured
    block with the material written inside it, the brand underneath. Somebody with
    a phone in one hand and the box in the other is reading one design instead of
    two.
    A block rather than the disc it was: the material has to sit inside the colour,
    and a word inside a circle either overflows the circle or shrinks it until the
    colour stops carrying - and the colour is how anyone recognises their own spool
    without reading. The text flips black or white on perceived brightness rather
    than an average of the channels, because the eye reads green as far b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
    [main.cpp]
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2026-09-06 Explain a failed connection instead of just failing
    After the five attempts the screen now says what happened and what to check:
    whether the printer is switched on, whether it is on this network, whether its
    settings are right in Tiger Studio Manager, and whether it has simply run out
    of connection slots - which is routine on Bambu A1, A1 Mini, A2L, P1 and P1S
    and is the cause nobody guesses.
    A QR code carries the long version to wiki.tigersystem.io rather than the panel
    carrying it. Four causes do not fit on 240 pixels, and a wiki page can be
    corrected the day a new printer joins that list while a string compiled into
    firmware cannot.
    Also fixes a bug this same work introduced one release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
    [main.cpp, screen_slots.cpp]
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2026-09-06 Stop rebooting, stop freezing, and read the whole chip
    The freeze in the NFC tester was a reboot, and the backtrace named it in one
    line: lv_label_set_text called from showWifi, on a heap assert about a pointer
    outside the heap. Every settings screen shared one signature variable and each
    folded its own constant into a hash of its contents - which is not a namespace.
    The tester hashes the tag's product id, so scanning a particular spool and then
    walking back through Settings could make the Wi-Fi screen believe nothing had
    changed and write into a label LVGL had already destroyed. Which spool you
    scanned decided whether the device crashed. Screens claim their view by
    identity now, not by a nu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
2026-09-07 Refresh the brand mirror after fixing two names upstream
    Duramic 3D and Filament PM were stored with a no-break space between the words
    instead of an ordinary one - a copy-paste artefact that looks identical in a
    text field and renders as a blank box on any display whose font does not carry
    U+00A0. Corrected in the TigerTag database itself, which is where it mattered:
    the generator here already repaired it, but the Python and JS SDKs, Studio
    Manager and the mobile app all read the value as it comes.
    No firmware change follows. tigertag_db.h is byte-for-byte identical, because
    the repair was already happening at generation time; what changed is that there
    is now nothing to repair.
    Checked a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
2026-09-07 Write French in French
    Every accent was missing from the interface, and not by choice: LVGL's built-in
    Montserrat faces carry ASCII, a degree sign and a bullet, and draw anything else
    as a blank box while logging nothing. The translation had been written around
    that - Reglages, Ecran, Mise a jour, Redemarrer le boitier - which reads as a
    product nobody proof-read rather than as a font that could not cooperate.
    The faces are generated now, from the same two source fonts LVGL uses and with
    LVGL's own symbol list, over 0x20-0x7F,0xA1-0x17F,0x2022. One face per size
    replacing the built-in rather than a fallback chain behind it: same metrics,
    same LV_SYMBOL_*, wider alphabet. The built-ins are s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
2026-09-07 Ask once, offer two answers
    Restart said "Restart" in its header, asked "Restart the box?" underneath, and
    offered a button marked "Restart" - one word, three times - with a note on how
    long it takes and a promise that nothing is lost. Factory reset listed what it
    erased and then reassured you about what came back, two paragraphs arguing over
    how frightening its own button should be. Both are now a question and two
    answers, and nothing else.
    Factory reset also loses its two-second hold. The hold against a filling bar
    was safer on paper and much less obvious in the hand: the bar had to be
    learned, and a stray press followed by a stray hold is not that much rarer than
    a stray press. A button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
    [main.cpp]
2026-09-07 Give the confirm buttons room to be missed
    They ran the full width, which reads as a bar rather than as something to
    press, and they touched each other - Restore and Cancel two pixels apart on a
    capacitive screen, one of which cannot be undone. Both narrower, with a gap.
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2026-09-07 Speak Elegoo and Anycubic on the LAN
    Both were the last two 🔵 rows on the compatibility page: protocols fully
    documented and proven on real hardware by Tiger Studio, with no firmware
    backend behind them. They have one now.
    Elegoo is MQTT on 1883 with no TLS, and it is two protocols wearing one badge -
    a cable decides which. With the Canvas hub plugged in, four trays read through
    method 2005 and write through 2003; without it, a single spool reads through
    1061 and writes through 1055, and 2003 answers error_code 1003 rather than
    doing anything. The backend follows whichever is live rather than assuming.
    Anycubic is MQTT on 9883 with TLS against a self-signed certificate, and its
    layout i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
    [backend_anycubic.cpp, backend_elegoo.cpp, main.cpp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]
2026-09-07 Carry every printer, and knock on the right door
    The eight-printer limit was worse than a limit. The import walks the six brands
    in a fixed order and stops when it is full, so an account with more printers
    did not lose a random eight - it lost the LAST BRANDS, every time. Elegoo and
    Anycubic are last, which meant the two backends added yesterday supported
    printers that could never appear on the device. Twenty-four now: a bench
    account of twelve imports whole and NVS reports 278 of 630 entries used.
    The reachability probe has a port per brand and falls back to Creality's 9999
    for anything it does not know, so both new brands were probed on a port they do
    not open, marked unreachable, and nev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
    [backend_anycubic.cpp, main.cpp, tigertag_cloud.cpp]
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2026-09-07 The credentials were never missing
    Elegoo would not authenticate and Anycubic would not connect, and both looked
    like gaps in the user's account. They were not. The import kept two lists of
    field names forty lines apart: a server-side mask deciding what Firestore sent,
    and a client-side filter deciding what the parser kept. Three fields were added
    to the first and not the second, so Firestore sent mqttPassword, username and
    acuModelId and the parser discarded all three before anything could read them.
    The account had every one of them the whole time.
    It is one list now, asked twice. The two do different jobs - the mask cuts
    bytes on the wire, the filter cuts nesting depth in the parser - an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
    [screen_slots.cpp, tigertag_cloud.cpp]
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2026-09-08 Measure what a printer session costs, instead of guessing
    I said three simultaneous printer connections would not fit and cited the
    account sync, the OTA check and the table update - three TLS clients where the
    third gets a refused connection. That is true and it is the wrong comparison.
    Those three verify against the Arduino core's root CA bundle, and parsing it is
    most of what they cost. A printer session is setInsecure() and pays none of it.
    Measured on this board, free internal RAM from a 199 936 byte baseline:
    plain TCP session (Elegoo MQTT 1883) ~3 KB, ~0.6 KB for a second
    TLS session, insecure (Anycubic MQTT 9883) ~38 KB
    two plain + one TLS, all open 158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
    [main.cpp]
2026-09-08 Hold every printer open, and make Snapmaker work at all
    Each printer left switched on in Settings now keeps its own live session,
    whatever screen is in front of the user, so opening one is instant. Four brands
    were held open together on the bench - Creality, Snapmaker, Elegoo, Anycubic.
    It is done the cheap way, deliberately: one link per BRAND. The backends are
    singletons per brand and a fleet is usually one machine per brand, so an array
    of links buys simultaneous sessions without touching a single backend. Two
    printers of the same brand still cannot both connect; that needs instancing,
    and it is the day this design ends. The cost was measured before any of it was
    written - about 3 KB for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
    [backend_snapmaker.cpp, main.cpp, screen_slots.cpp]
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2026-09-08 Put the refresh button where printers are missed
    It went into the home header first, which was the wrong screen and cost the
    title a size to fit. Settings > Printers is where somebody notices a printer
    they just added has not arrived, and its header carries a chevron and nothing
    else - so the button fits at full size and the home screen goes back to exactly
    what it was.
    Still its own progress indicator: amber while the sync runs.
    [main.cpp]
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2026-09-08 Show cloud printers, and say what they cannot do
    A Bambu Lab printer in cloud mode was dropped at import, so a machine the user
    owns was simply absent from the device and nothing explained the gap. They are
    listed now, and opening one says what it is - cloud printer, read only - with a
    QR to the page about switching it to LAN mode.
    Their slots are not tappable. Bambu's cloud broker accepts a report
    subscription and refuses the command that sets a tray, so a cell that looked
    pressable there could never do anything, which is worse than one that plainly
    is not. A cloud printer is also never probed and never given a link: it costs
    nothing to list something that has nothing on this network to di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
    [main.cpp, screen_slots.cpp, tigertag_cloud.cpp]
2026-09-08 Show a screen while the account is read, not a coloured glyph
    The read takes about fifteen seconds. A tinted icon in the corner of a header
    is a still picture, and a still picture is what makes somebody press the button
    again - so the refresh now opens a screen that says "Importing printers" over a
    ring that actually turns, and returns to the rebuilt list when the answer is
    in. It also keeps the list from being touched in the moment before it changes
    underneath.
    The button itself leaves the main printer list. It belongs on the screen where
    a missing printer is noticed and acted on, and taking it off gives the main
    screen its full-size title back - it was the only reason that title had shrun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
    [main.cpp]
2026-09-08 Read a Bambu printer that is only on the cloud
    The device connects to Bambu's own regional broker with the session Tiger
    Studio wrote into the account - it never signs in to Bambu itself - and the
    report that comes back is byte-for-byte the one the LAN path already parses, so
    nothing in the parser moved. An X1C reachable only through the cloud now shows
    Ext. and B1..B4 on the panel.
    Tapping one of those slots answers with why it cannot be written, on a screen
    of its own with a QR to the page about switching to LAN mode. The cell stays
    tappable on purpose: one that silently ignores a finger teaches nothing.
    What made it possible was a rule that had been wrong since links became
    plural. One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
    [backend_bambu.cpp, main.cpp, screen_slots.cpp]
2026-09-08 Say it once, in orange, with a QR a scanner can read
    The cloud slot notice carried a title and an explanation. It is one message
    now - "Working only with LAN Mode + Dev Mode" - with "Scan for tutorial" under
    the code.
    The code was also off-centre and touching the white edge. The card had a
    pad_top, and lv_obj_align measures from the parent's CONTENT area, so that
    padding pushed the code down and right inside a card sized for it being
    flush. Same construction as the failure screen now: no padding, card sized
    from the code's measured width, code pinned at the quiet zone.
    ?preview=cloudslot renders it without navigating to a cloud printer.
    [screen_slots.cpp]
2026-09-08 A sync that reached one brand no longer deletes the other five
    Pressing reload with six links open turned a list of thirteen printers into a
    list of three. Five of the six Firestore requests had failed - not enough
    contiguous heap for a TLS session - and the import wrote its result as if it
    were the whole account. Bambu, FlashForge, Snapmaker, Elegoo and Anycubic were
    erased from a device that had simply been unable to ask about them.
    A brand that does not answer is not a brand with no printers. It contributes
    what was stored for it last time, in its own place in the list. Verified by
    forcing two brands to fail: "7 LAN, 6 kept - no change", nothing written.
    Second fix in the same import: t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
    [tigertag_cloud.cpp]
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2026-09-09 Links that come back on their own, and an interface that keeps answering
    Three faults, all of which showed up as the same thing: printers whose dot went
    red and stayed red until somebody tapped them.
    A link that ran out of attempts never dialled again. That is a box which, left
    alone through one Wi-Fi blink or one printer reboot, ends the afternoon with
    every dot red and only a finger to bring them back - the retry button was
    correcting a defect rather than serving impatience. Giving up is a minute's
    pause now.
    The interface froze whenever the network went bad. Opening a connection blocks
    the loop, and the defaults are enormous: fifteen seconds on a PubSubClient
    socket, two minutes on an A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
    [backend_anycubic.cpp, backend_bambu.cpp, backend_elegoo.cpp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]
2026-09-09 Give the room back when a handshake needs it
    With six printers connected this device reports 66 KB free and a largest
    contiguous block of 29 KB. A TLS session needs about 40 KB in one piece, so
    every HTTPS request failed instantly: the account refresh, and the update
    check, which is what put "manifest HTTP -1" on the update screen. A device that
    cannot fetch its own manifest cannot update itself.
    The admission rules watched the free TOTAL and never the shape of the heap, and
    a reserve cannot fix that: a block big enough for TLS is most of what the links
    are using, held permanently for something that happens for two seconds every
    few minutes. So the background links stand down while a handsh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
    [main.cpp]
2026-09-09 Ask for Wi-Fi again when it goes away
    Wi-Fi was dialled once at boot and never again. If the association failed at
    startup, or the access point dropped the device later, it sat there with a lit
    screen, every printer red and no route to the account - for ever. Watched
    happening twice in one afternoon on a link measured at -80 dBm, once at boot
    and once mid-session; Arduino's own auto-reconnect brought it back neither time.
    After fifteen seconds down it asks again, and keeps asking every thirty. A box
    left alone on a bad afternoon has to end up connected, because nobody is going
    to power-cycle it.
    This is very likely what was behind "everything is closed" earlier, which had
    been put down to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
    [main.cpp]
2026-09-09 The NFC tester says what is on the chip
    It was a spool card that happened to list fields. It is a bench instrument now,
    and the difference decides every choice in here.
    English in every language, because it is read beside a reader log, a datasheet
    and the TigerTag SDK, all of which are in English - two people comparing the
    same spool in two countries have to be looking at the same words. The labels
    still go through the translation table, with eight identical rows and a comment
    saying why.
    One field per row. Kind and diameter shared a line, and so did drying
    temperature and time, on the reasoning that they read well together - which is
    the wrong reasoning here: two values joined by a slash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
    [main.cpp, reader.cpp]
2026-09-10 Stop asking Bambu for everything it already sends
    The backend asked for a full `pushall` every eight seconds. Measured on two
    printers over 150 seconds: forty answers, 4.9 KB each, 81 KB a minute - for
    trays that had not moved.
    None of it was needed. The printer publishes an AMS report by itself the moment
    a spool changes, and that report is 1210 bytes rather than 5906. A slot changed
    by hand arrived on its own 164 seconds after the last request this device made,
    which is the measurement that settles it: not a reply to anything of ours.
    What is left is one pushall at connect, one every five minutes as a backstop
    against a report missed while a socket was down, and one when a printer's
    scre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
    [backend_anycubic.cpp, backend_bambu.cpp, backend_elegoo.cpp]
2026-09-10 Measure what a printer costs, and correct what was assumed
    /api/memtest closes every link, holds the account sync off, and opens printers
    one at a time, reading each one's cost after ten settled seconds. It exists
    because the numbers taken in normal running were not facts about any printer:
    links opened in groups and an account sync allocated a TLS session in the
    middle, so the per-link deltas added up to 193 KB against 135 KB measured on
    the whole.
    What it found overturns the model the admission rules were built on. The MQTT
    buffers are not in internal RAM - this framework is compiled with
    CONFIG_SPIRAM_USE_MALLOC and a 4 KB threshold, so every allocation over that,
    the 50 KB Bambu buffer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
    [backend_bambu.cpp, main.cpp]
2026-09-10 One TLS session for every Bambu printer on a cloud account
    A TLS session is what a printer costs on this device - about 45 KB of internal
    RAM, measured - and it is what limits how many printers can be open at once.
    Every Bambu printer in cloud mode on one account talks to the same regional
    broker with the same credentials; only the topic differs. So they now share one
    session: the first cloud printer opens it, each further one only subscribes to
    device/<serial>/report on it, and the last to leave closes it.
    Measured with /api/memtest, two cloud printers on the bench:
    second cloud Bambu 47.8 KB -> 3.2 KB
    six links, free RAM 60 KB -> 99 KB
    largest free block 18 KB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
    [backend_bambu.cpp, bambu_cloud.cpp, main.cpp]
2026-09-10 A loop that stops must not stay stopped
    The main loop froze once during testing: panel lit, every printer frozen on
    screen, no reply on the network and no line on the console. Nothing was
    watching it - the task watchdog only watched the idle task - so it would have
    stayed frozen until somebody cut the power.
    It is under the watchdog now, with thirty seconds: longer than the slowest
    legitimate thing the loop does, which is a TLS connect, so a slow printer
    cannot trip it. A pass that does not come back panics, prints a backtrace of
    where it was stuck, and reboots into a working device. It joins on the first
    pass rather than in setup(), because setup() waits on Wi-Fi at boot and that
    wait is s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
    [main.cpp]
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2026-09-11 Nearest access point, and a header that lines up
    The device joined the first access point it heard with the network's name and
    cached it through every reboot - on a multi-AP network, -79 dBm while the same
    network was at -46 one room away. staBegin() erases that and connects by
    signal, as the TigerScale does. The home header's three icons now share one
    height and even spacing, all three open Settings, and the Wi-Fi icon shows
    full signal from -60 dBm. /api/scan?all=1 lists every radio the device hears.
    [main.cpp]
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2026-09-23 Release 1.67.0
    The account page manages the account: picture, name and address, a
    sign-out that asks first, and a drawer with every printer, an on/off
    switch each (applied by main.cpp through the device's own budget check)
    and a sync that redraws the list in place.
    Email sign-in no longer resets the device: web handlers ask for a sync
    instead of running one on the loop task's 8 KB stack (#15).
    Docs: stale CODEMAP rows on gen_db.py and battery presence, and AGENTS
    rows on ASCII-only fonts and Chinese, now match the code.
    [main.cpp, tigertag_cloud.cpp]
2026-10-03 Creator 5 case: corrected frame, Fusion source, and a Flash Studio project
    [tigerspool-creator5-frame.3mf, tigerspool-creator5-full.3mf, tigerspool-creator5.f3d]
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

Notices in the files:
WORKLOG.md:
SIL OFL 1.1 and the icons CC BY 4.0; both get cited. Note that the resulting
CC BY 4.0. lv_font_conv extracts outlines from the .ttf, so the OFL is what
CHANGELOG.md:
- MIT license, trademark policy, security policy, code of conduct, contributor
